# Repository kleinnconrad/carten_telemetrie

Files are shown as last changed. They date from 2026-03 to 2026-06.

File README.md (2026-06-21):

# Carten Telemetrie

## Inhaltsverzeichnis
* [1. Projektbeschreibung und Spezifikationen](#1-projektbeschreibung-und-spezifikationen)
* [2. Stückliste (Bill of Materials)](#2-stueckliste-bill-of-materials)
* [3. Schaltplan und Systemarchitektur](#3-schaltplan-und-systemarchitektur)
* [4. Implementierung und Aufbau](#4-implementierung-und-aufbau)
  * [4.1 Software und Firmware-Kompilierung](#41-software-und-firmware-kompilierung)
  * [4.2 Elektrische Verkabelung](#42-elektrische-verkabelung)
  * [4.3 Mechanische Integration](#43-mechanische-integration)
* [5. Betriebsmodus und Datenauswertung](#5-betriebsmodus-und-datenauswertung)
* [6. CI/CD: Reddit-Feedback-Synchronisation](#6-cicd-reddit-feedback-synchronisation)

## 1. Projektbeschreibung und Spezifikationen

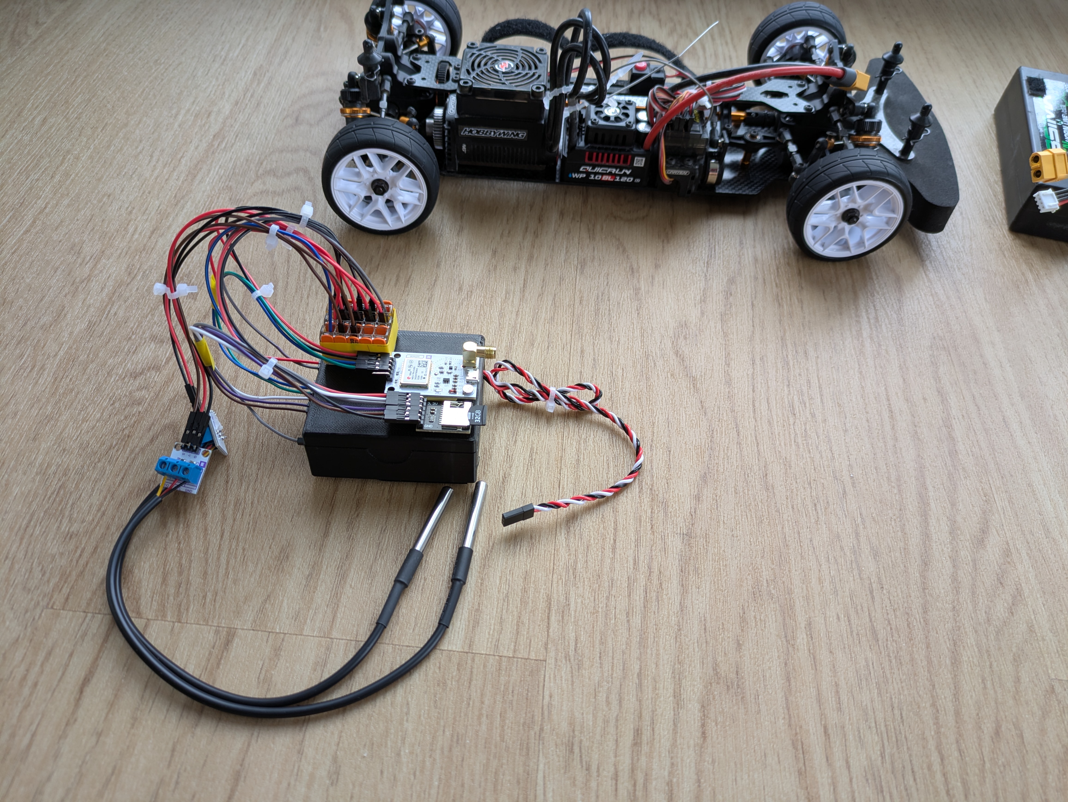
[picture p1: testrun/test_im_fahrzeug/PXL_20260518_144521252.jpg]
Test im Fahrzeug - Setup 1
 Carten Telemetrie Setup im Fahrzeug

Entwicklung eines lokalen Telemetriesystems für das ferngesteuerte Modellfahrzeug Carten T410R . Das System erfasst dynamische und thermische Parameter während des Fahrbetriebs.

**Erfasste Metriken und Spezifikationen:**
* **Temperatur:** Erfassung von Motor- und ESC-Temperaturen (Messbereich -55°C bis +125°C, Auflösung 12-Bit) über den 1-Wire-Bus.
* **Drehzahl:** RPM-Erfassung der Kardanwelle mittels Hall-Effekt-Sensor und Neodym-Magnet (Hardware-gestützter Pulse Counter).
* **Geodaten:** Aufzeichnung von Längen- und Breitengrad sowie der absoluten Geschwindigkeit (GNSS/GPS-Satellitendaten via NMEA 0183-Protokoll, Updaterate 1 Hz bis 10 Hz konfigurierbar).

**Architektur-Variante:**
* Ausschließliches Offline-Logging auf einer lokalen MicroSD-Karte. Zur Vermeidung von Latenzen und Verbindungsabbrüchen findet keine Datenübertragung über drahtlose Netzwerke statt.

## 2. Stückliste (Bill of Materials)
Für die Nachkonstruktion sind zwingend die folgenden Bauteile oder äquivalente Spezifikationen zu verwenden:

| Komponente | Spezifikation / Typ | Funktion im System |
| :--- | :--- | :--- |
| Microcontroller | ESP32 Dev Board (30-Pin Variante, z.B. NodeMCU) | Zentrale Ingestion und Verarbeitung der Sensorik |
| Erweiterungsboard | ESP32 Terminal Breakout Board (30-Pin) | Sichere Kontaktierung der Jumper-Kabel ohne Löten |
| GPS-Modul | BN-220 (u-blox M8N) | Bereitstellung der Geodaten (Baudrate 9600) |
| Speichermodul | MicroSD-Karten-Modul (SPI) | Persistenter Datenspeicher (zwingend 3.3V Logik) |
| Temperatursensor | DS18B20 (TO-92 oder wasserdicht) | 2x Sensoren zur Temperaturüberwachung (Motor, ESC) |
| Drehzahlsensor | Hall-Sensor Modul (A3144) | Detektion von Magnetfeldänderungen |
| Magnet | Neodym-Magnet (3x2mm) | Rotierender Impulsgeber an der Kardanwelle |
| Stromversorgung | 3-Pin Servokabel (JR-Stecker) | 5V Spannungsabgriff über das BEC des RC-Empfängers |

## 3. Schaltplan und Systemarchitektur
Alle Hardwarekomponenten nutzen eine gemeinsame Masse (GND) zur Vermeidung von Floating-Potenzialen. Die serielle UART-Verbindung zwischen ESP32 und GPS-Modul erfordert eine physikalische Kreuzung der Leitungen (TX an RX, RX an TX). Der Spitzenstrombedarf des Gesamtsystems liegt bei etwa 200 mA bis 250 mA.

| Komponente | Interface | ESP32 Pin | Sensor Pin | Bemerkung |
| :--- | :--- | :--- | :--- | :--- |
| RC-Empfänger| Power | `VIN` | 5V (Rot) | Parasitäre Versorgung über ESC/Empfänger (BEC) |
| | | `GND` | GND (Schwarz)| Referenzpotenzial |
| GPS Modul| UART 2 | `GPIO 16` (RX2) | TX | VCC-Spannungsversorgung zwingend über 3.3V des ESP32 |
| | | `GPIO 17` (TX2) | RX | |
| MicroSD-Modul | SPI | `GPIO 23`, `19`, `18`, `5` | MOSI, MISO, SCK, CS | VCC-Spannungsversorgung zwingend über 3.3V des ESP32 |
| DS18B20 | 1-Wire | `GPIO 4` | DQ (Daten) | Parallelschaltung beider Sensoren |
| A3144 Hall-Sensor| Dig. Out | `GPIO 2` | DO (Signal) | Anbindung an ESP32 PCNT (Pulse Counter) |

*(Der detaillierte visuelle Schaltplan befindet sich im Verzeichnis `/schaltplan`.)*

## 4. Implementierung und Aufbau

### 4.1 Software und Firmware-Kompilierung
* **Umgebung:** Die Kompilierung erfordert PlatformIO oder die Arduino IDE.
* **Bibliotheken:** Zur Übersetzung des Quellcodes müssen `TinyGPSPlus`, `OneWire` und `DallasTemperature` im Library-Manager installiert sein.
* **Flash-Vorgang:** Die Firmware ist via USB-Schnittstelle auf den ESP32 zu überspielen. Bei Boot-Problemen ist der serielle Output (`115200` Baud) auf Initialisierungsfehler (z.B. SD-Karte nicht gefunden) zu prüfen.

### 4.2 Elektrische Verkabelung
* Der ESP32 ist auf das Terminal-Breakout-Board aufzustecken. Alle Jumper-Kabel werden zwingend in den Schraubklemmen des Breakout-Boards fixiert, um vibrationsresistente Verbindungen zu gewährleisten.
* Das Servokabel ist polungsrichtig über Jumper-Kabel mit den `VIN`- (5V) und `GND`-Klemmen zu verschrauben und an einen freien Port des RC-Empfängers anzuschließen.
* Die Verbindung von GPS, SD-Modul, Hall-Sensor und Temperatursensoren ist gemäß der dokumentierten Pin-Belegung mittels Jumper-Kabeln und den Klemmen des Breakout-Boards vorzunehmen.
* Bei Mehrfachbelegungen (z. B. der Zusammenführung mehrerer GND- oder 3.3V-Leitungen der Sensoren) sind WAGO-Klemmen einzusetzen. Zur Vermeidung von Wackelkontakten bei Vibrationen ist der korrekte Sitz in den Klemmen zu prüfen.

### 4.3 Mechanische Integration
* **Zentraleinheit:** Die Befestigung des ESP32-Gehäuses im Chassis erfolgt über verschraubte Trägerplatten oder Klettband.
* **GPS:** Das GPS-Modul muss horizontal montiert werden. Die Keramik-Antenne muss ungehindert nach oben zeigen.
* **Drehzahlmessung:** Der Neodym-Magnet ist adhäsiv (z.B. Sekundenkleber oder Epoxidharz) auf der Kardanwelle zu fixieren. Ein entsprechendes Gegengewicht auf der gegenüberliegenden Seite der Welle verhindert Unwuchten bei hohen Rotationsgeschwindigkeiten. Der Hall-Sensor ist mit einem Spaltmaß von maximal 2 mm über dem Magneten starr zu positionieren.
* **Temperaturen:** Die DS18B20-Sensoren sind mit Wärmeleitkleber an ESC und Motorgehäuse anzubringen.

## 5. Betriebsmodus und Datenauswertung
* **Boot-Sequenz:** Das System startet autonom beim Einschalten des RC-Fahrzeugs. Nach erfolgreicher Initialisierung des SPI-Busses beginnt der Schreibvorgang.
* **Logging-Zyklus:** Die Sensordaten werden mit einer Frequenz von 2 Hz auf die MicroSD-Karte geschrieben. Die Limitierung auf 2 Hz verhindert Schreib-Puffer-Überläufe (Buffer Overruns) der SD-Karte.
* **Datenformat:** Die Ausgabe erfolgt als standardisierte CSV- oder JSON-Datei auf einer FAT32-formatierten Partition.
* **Post-Processing:** Nach Abschluss der Fahrt ist die MicroSD-Karte manuell zu entnehmen. Die Rohdaten können in Tabellenkalkulationsprogrammen oder Analyse-Skripten visualisiert und evaluiert werden.

## 6. CI/CD: Reddit-Feedback-Synchronisation
Eine konfigurierte GitHub Action dient der Extraktion von externem Projektfeedback aus dem verlinkten Reddit-Thread.

### Architektur
* **Python-Skript (`scripts/fetch_reddit.py`):** Verantwortlich für den Abruf des Reddit-RSS-Feeds und die HTML-Bereinigung der Kommentare.
* **Automatisierung (`.github/workflows/reddit-sync.yml`):** Der Cronjob triggert die Pipeline arbeitstäglich um 08:00 UTC.
* **Output-Handling:** Neu erfasste Kommentare werden in die Datei `reddit/reddit_feedback.md` geschrieben und durch die Action automatisch im `main`-Branch committet.

### Manueller Sync
Zur sofortigen Datensynchronisation:
* Im GitHub-Repository den Tab "Actions" öffnen.
* Den Workflow "Fetch Reddit Feedback" selektieren.
* "Run workflow" ausführen. Die Markdown-Datei wird daraufhin aktualisiert.

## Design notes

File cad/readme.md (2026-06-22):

# ESP32 Sensor-Station und Gehäuse

## Inhaltsverzeichnis
* [1. Übersicht](#1-übersicht)
* [2. Dateiliste](#2-dateiliste)
* [3. Hardware-Komponenten](#3-hardware-komponenten)
* [4. Druckparameter und Material](#4-druckparameter-und-material)
* [5. Montagehinweise](#5-montagehinweise)
* [6. Quellen](#6-quellen)

## 1. Übersicht
Dieser Ordner enthält die 3D-Druck-Dateien (STL) für die Fertigung der ESP32-Sensor-Station. Das mechanische Konzept besteht aus einem Schutzgehäuse für den Mikrocontroller und einem passgenauen Trägerboard zur Montage der Sensor- und Speichermodule innerhalb des RC-Chassis. Ziel ist der Schutz vor mechanischen Stößen, Staub und Spritzwasser sowie die Zugentlastung der Kabel.

## 2. Dateiliste

| Dateiname | Beschreibung | Herkunft |
| :--- | :--- | :--- |
| `esp32-30pin-breakoutboard-case.stl` | Unteres Gehäuseelement für das ESP32 Development Board (30-Pin Variante) inklusive des Terminal-Breakout-Boards. | Extern |
| `esp32-30pin-breakoutboard-lid.stl` | Deckel für das ESP32-Gehäuse mit Snap-Fit-Mechanismus (Einrast-Verschluss). | Extern |

## 3. Hardware-Komponenten
Die CAD-Konstruktion ist maßlich exakt auf folgende Hardware ausgelegt:
* Mikrocontroller: ESP32 Development Board (30 Pins, z.B. Freenove oder NodeMCU)
* Erweiterung: Terminal-Breakout-Board für 30-Pin ESP32 (Schraubklemmen)
* Sensoren: 2x DS18B20 (TO-92 Bauform oder vorkonfektioniert)
* Speicher: 1x MicroSD-Karten-Modul (Standard-SPI-Modul)
* Ortung: 1x GPS-Modul (BN-220, Maße: 22x20x6 mm)

## 4. Druckparameter und Material
Aufgrund der thermischen Belastung im RC-Fahrzeug (Nähe zu Motor und ESC) sowie der mechanischen Vibrationen gelten folgende Vorgaben für die additive Fertigung:

* **Material:** PETG, ASA oder ABS (PLA ist wegen der niedrigen Glasübergangstemperatur von ca. 60°C nicht zulässig).
* **Schichthöhe (Layer Height):** 0.20 mm für ein optimales Verhältnis aus Stabilität und Druckzeit.
* **Fülldichte (Infill):** Mindestens 30% (Gyroid oder Cubic Pattern), um strukturelle Integrität bei Stößen zu gewährleisten.
* **Wandlinien (Perimeters):** 3 bis 4 Linien zur Erhöhung der Biegesteifigkeit.
* **Toleranzen:** Das Modell beinhaltet ein Spaltmaß von 0.2 mm für den Snap-Fit-Deckel. Bei Überextrusion muss der Fluss (Flow Rate) im Slicer kalibriert werden.

## 5. Montagehinweise
* Die Platinen (GPS, SD-Modul) werden mit M2- oder M2.5-Schrauben auf der Trägerplatte `sensor_board_.stl` fixiert. Bei Bedarf sind Heiß-Einpressmuttern (Threaded Inserts) zu verwenden.
* Die Antenne des BN-220 GPS-Moduls (keramische Oberseite) muss zwingend nach oben zeigen und darf nicht durch Carbon- oder Metallbauteile des Chassis verdeckt werden.
* Kabeldurchführungen am Gehäuse müssen nach Abschluss der Verkabelung zur Zugentlastung mit einem Tropfen Schmelzklebstoff gesichert werden.

## 6. Quellen
* Modell: [ESP32 30-pin breakout board case + snap fit lid](https://www.printables.com/model/856471-esp32-30-pin-breakout-board-case-snap-fit-lid/files)
* Ersteller: [@Goofee_2018635 auf Printables](https://www.printables.com/@Goofee_2018635)

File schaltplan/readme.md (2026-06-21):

# RC-Telemetrie-System

## Inhaltsverzeichnis
* [1. System-Architektur](#1-system-architektur)
* [2. Schaltplan](#2-schaltplan)
* [3. Pin-Mapping](#3-pin-mapping)
* [4. Stromversorgung](#4-stromversorgung)
* [5. Schaltplan Generierung](#5-schaltplan-generierung)
* [6. Betrieb](#6-betrieb)

Dieses System erfasst Telemetriedaten (Geschwindigkeit, Drehzahl, Temperaturen) in einem RC-Fahrzeug als lokales Data-Logging.

## 1. System-Architektur
* Betriebsmodus: Batch-Logging auf MicroSD-Karte.
* GPS-Tracking: Ein GPS-Modul liefert Geodaten und Geschwindigkeitswerte via NMEA-Protokoll (Hardware-UART).
* Logging: Die MicroSD-Karte dient als primärer Speicher.
* Sensor-Auslesen: Die Erfassung erfolgt asynchron. Impulse des Hall-Sensors werden über einen Hardware-Zähler (PCNT) registriert.

## 2. Schaltplan

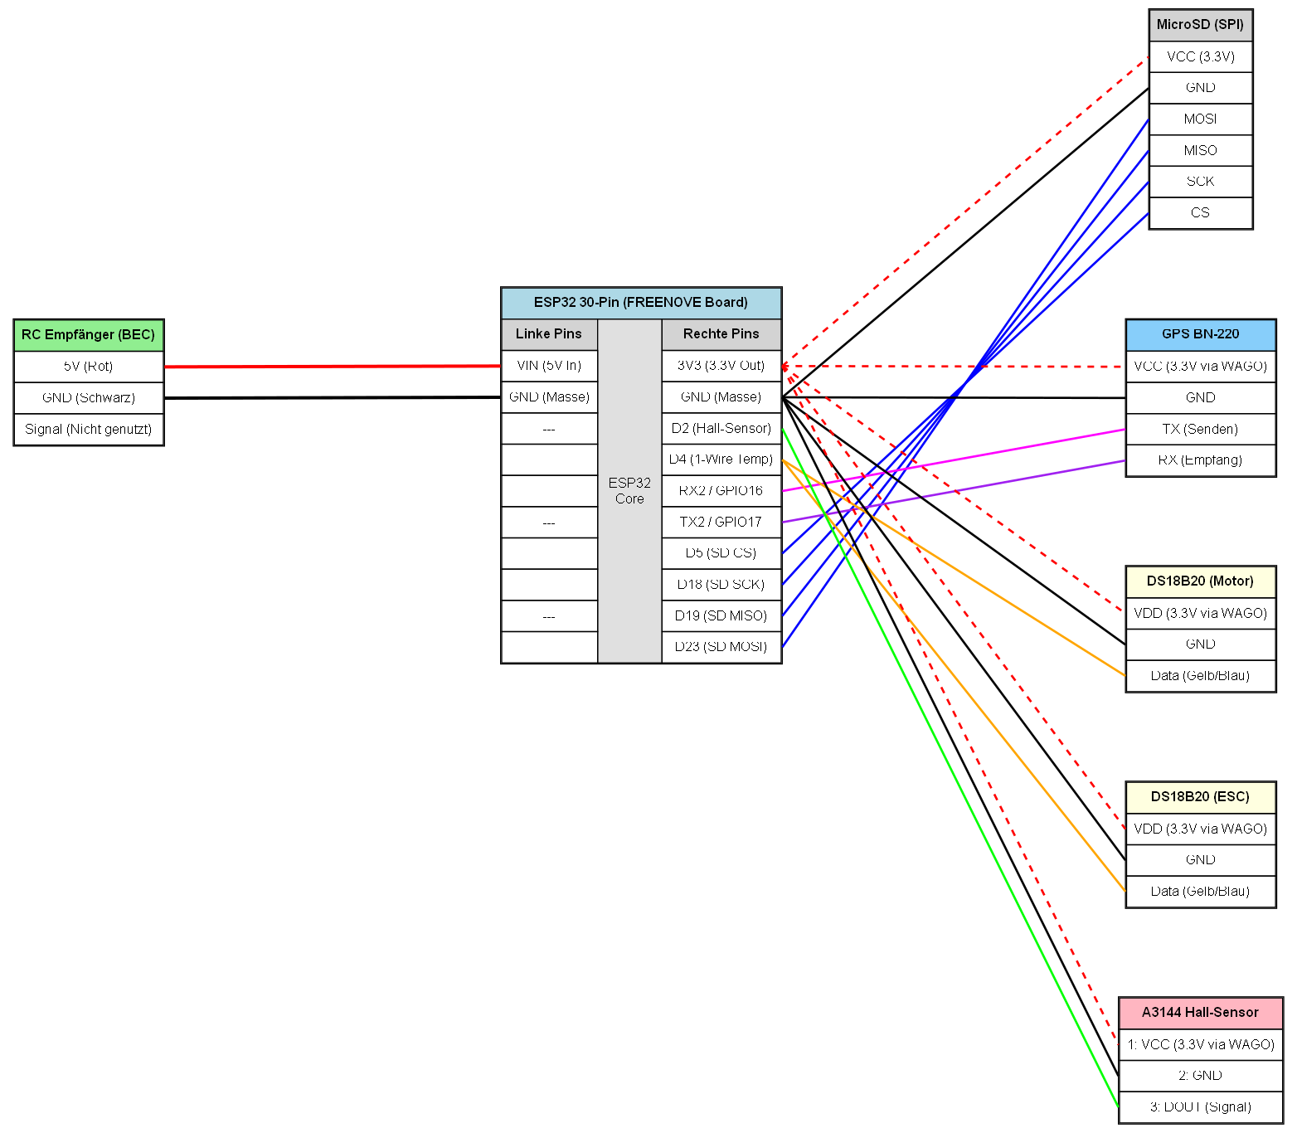
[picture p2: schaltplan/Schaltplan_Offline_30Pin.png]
Schaltplan Offline


## 3. Pin-Mapping
Alle Komponenten benötigen eine gemeinsame Masse (GND). Serielle Verbindungen erfordern gekreuzte Leitungen (TX an RX, RX an TX).

| Komponente | Interface | ESP32 Pin | Sensor Pin | Bemerkung |
| :--- | :--- | :--- | :--- | :--- |
| RC-Empfänger | Power | `VIN` | 5V (Rot) | Versorgung über ESC/Empfänger |
| | | `GND` | GND (Schwarz)| Gemeinsame Masse |
| GPS Modul | UART 2 | `GPIO 16` (RX2) | TX | VCC an 3.3V ESP32 |
| | | `GPIO 17` (TX2) | RX | |
| MicroSD-Modul | SPI | `GPIO 23`, `19`, `18`, `5` | MOSI, MISO, SCK, CS | VCC an 3.3V ESP32 |
| DS18B20 (Motor)| 1-Wire | `GPIO 4` | DQ | |
| DS18B20 (ESC)| 1-Wire | `GPIO 4` | DQ | Parallelschaltung |
| A3144 Hall-Sensor| Digital Out | `GPIO 2` | DO | PCNT-Nutzung |

## 4. Stromversorgung
ESP32 und Sensorik benötigen 150-250 mA. Die Versorgung erfolgt über den Motorregler (ESC) und Empfänger.
1. Anschluss eines Servokabels an den RC-Empfänger.
2. Rotes Kabel (5V) an den VIN-Pin des ESP32.
3. Schwarzes Kabel (GND) an den GND-Pin des ESP32.

## 5. Schaltplan Generierung
Der Schaltplan wird mit Python und `uv` erstellt.

1. System-Abhängigkeit (Alpine Linux):
   ```bash
   sudo apk add graphviz
   ```
2. Tool `uv` herunterladen:
   ```bash
   curl -LsSf https://astral.sh/uv/install.sh | sh
   source $HOME/.local/bin/env
   ```
3. Skript ausführen:
   ```bash
   uv run --with graphviz schaltplan.py
   ```

## 6. Betrieb
1. Boot: Systemstart bei Einschalten des RC-Fahrzeugs.
2. Log: Speicherung der Sensordaten mit 2 Hz auf der MicroSD-Karte.
3. Analyse: Manuelles Einlesen der MicroSD-Karte.

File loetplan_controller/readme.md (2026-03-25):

# RC-Telemetrie-System

Dieses System erfasst hochfrequente Telemetriedaten (Geschwindigkeit, Drehzahl, Temperaturen) in einem RC-Fahrzeug und streamt diese in Echtzeit über ein Mobilfunknetz (LTE) an ein Cloud-Backend (via MQTT). Die Architektur ist auf höchste Zuverlässigkeit und Systemsicherheit ausgelegt, inklusive einer vom RC-Antrieb komplett isolierten Stromversorgung.

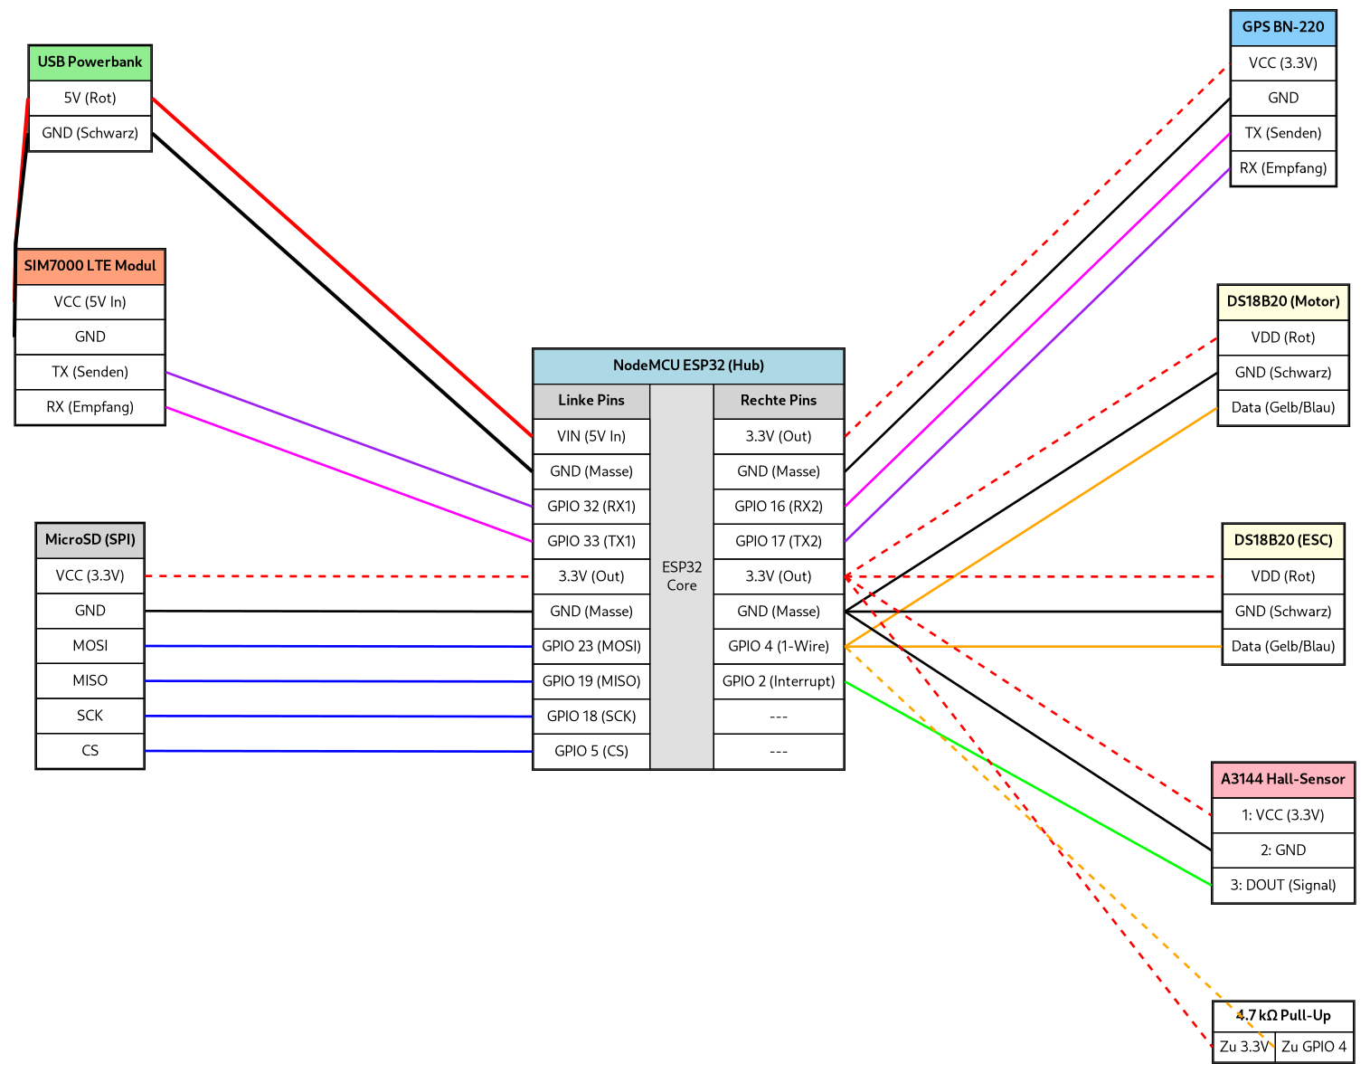
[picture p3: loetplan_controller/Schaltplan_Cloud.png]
schaltplan2


## 1. System-Architektur

* **Isolierte Stromversorgung:** Die gesamte Telemetrie-Elektronik wird über eine autarke 5V USB-Powerbank versorgt. Stromspitzen des LTE-Modems (bis zu 2A) können so keinen Brownout des RC-Empfängers verursachen.
* **Live-Streaming (LTE & MQTT):** Daten werden asynchron als JSON-Payloads via MQTT über ein SIM7000G LTE-Modul an die Cloud gesendet.
* **GPS Tracking:** Ein dediziertes GPS-Modul liefert echte Geodaten und hochpräzise Geschwindigkeitswerte via NMEA-Protokoll (Hardware-UART).
* **Lokales Backup (Ringpuffer):** Die MicroSD-Karte fungiert über den SPI-Bus als Fallback. Bei Verbindungsabbrüchen im Mobilfunknetz gehen keine Speedrun-Daten verloren.
* **Asynchrones Sensor-Auslesen:** Zeitintensive Operationen (wie die 750ms Wandlungszeit der DS18B20 1-Wire Sensoren) blockieren niemals den Main-Loop.

## 2. Pin-Mapping (Verkabelung)

**WICHTIG:** Alle Komponenten müssen sich eine gemeinsame Masse (**GND**) teilen. RX- und TX-Leitungen bei seriellen Verbindungen müssen immer überkreuzt angeschlossen werden (TX an RX, RX an TX).

| Komponente | Interface | ESP32 Pin | Sensor Pin | Bemerkung |
| :--- | :--- | :--- | :--- | :--- |
| **USB Powerbank** | Power | `VIN` | 5V Out | Speist ESP32 und LTE parallel |
| **LTE Modul (SIM7000)** | UART 1 | `GPIO 32` (RX1) | TX | VCC direkt an 5V Powerbank! |
| | | `GPIO 33` (TX1) | RX | |
| **GPS Modul (BN-220)**| UART 2 | `GPIO 16` (RX2) | TX | VCC an 3.3V vom ESP32 |
| | | `GPIO 17` (TX2) | RX | |
| **MicroSD-Modul** | SPI | `GPIO 23` | MOSI | |
| | | `GPIO 19` | MISO | |
| | | `GPIO 18` | SCK | |
| | | `GPIO 5` | CS | |
| **DS18B20 (Motor)** | 1-Wire | `GPIO 4` | DQ (Daten) | Benötigt 4.7kΩ Pull-Up an 3.3V |
| **DS18B20 (ESC)** | 1-Wire | `GPIO 4` | DQ (Daten) | Parallel zum Motor-Sensor schalten |
| **A3144 Hall-Sensor**| Digital Out | `GPIO 2` | DO (Signal) | Nutzt Hardware-Interrupt (`FALLING`) |

## 3. Autarke Stromversorgung (Power-Management)

Die zuverlässige Stromversorgung ist der kritischste Punkt dieses Cloud-Telemetrie-Systems. Das LTE-Modem (SIM7000) benötigt beim Senden im Mobilfunknetz kurzzeitig Stromspitzen von **bis zu 2 Ampere**. Würde man das Modem direkt an den 5V-Ausgang des ESP32 anschließen, käme es sofort zu einem Spannungsabfall (Brownout) und der Controller würde unkontrolliert neu starten. 

Um dies zu verhindern, nutzen wir eine isolierte Parallel-Schaltung mittels eines **USB Breakout-Boards**. 

### Benötigte Komponenten
* 1x Standard USB-Powerbank (5V, min. 2.1A Output)
* 1x USB Breakout-Board (Passend zum Anschluss der Powerbank, meist USB-A oder USB-C)
* Kupferlitze (Empfehlung: AWG 22 für das LTE-Modul, um Kabelwiderstände zu minimieren)

### Physischer Aufbau (Die 5V-Weiche)

Das Breakout-Board fungiert als Y-Verteiler, der den ESP32 und das LTE-Modem unabhängig voneinander aus derselben Quelle speist:

1. **VCC (5V Pluspol):**
   * Nimm zwei rote Kabel (ein dickeres für LTE, ein Standard-Kabel für den ESP32).
   * Verzwirble die blanken Kupferenden beider Kabel miteinander.
   * Stecke die verzwirbelten Enden gemeinsam durch das Pad mit der Aufschrift `VCC` (oder `5V`) auf dem Breakout-Board und verlöte sie großzügig.
   * Führe das eine Kabel an den `VIN` (oder 5V) Pin des ESP32 und das andere an den `VCC` (5V In) Pin des LTE-Moduls.

2. **GND (Gemeinsame Masse):**
   * Wiederhole den exakt gleichen Vorgang mit zwei schwarzen Kabeln am `GND`-Pad des Breakout-Boards.
   * Führe ein Kabel an einen `GND` Pin des ESP32 und das andere an den `GND` Pin des LTE-Moduls. 
   * *Wichtig: Alle Komponenten des Systems (Sensoren, GPS, SD-Karte) müssen zwingend über den ESP32 mit diesem GND verbunden sein (Common Ground), da sonst die serielle Datenübertragung fehlschlägt.*

3. **Daten-Pins (D+ / D-):**
   * Diese Pins auf dem Breakout-Board werden komplett ignoriert, da die USB-Verbindung rein der Stromversorgung dient.

Sobald das Breakout-Board in die Powerbank gesteckt wird, fahren beide Module parallel hoch, ohne sich bei Stromspitzen gegenseitig zu beeinflussen.

## 4. Schaltplan generieren (mit `uv`)

Um den visuellen Lötplan als PNG zu generieren, nutzen wir Python und das Tool `uv`, um die Abhängigkeit (`graphviz`) nicht global im System installieren zu müssen.

**graphviz:**

1. System-Abhängigkeit installieren (Alpine Linux):
   ```bash
   sudo apk add graphviz
   ```

2. Tool `uv` herunterladen und Pfad laden:
   ```bash
   curl -LsSf [https://astral.sh/uv/install.sh](https://astral.sh/uv/install.sh) | sh
   source $HOME/.local/bin/env
   ```

3. Skript ausführen:
   ```bash
   uv run --with graphviz loetplan.py
   ```

## 5. Betrieb

1. **Boot:** Nach dem Verbinden der USB-Powerbank initialisiert der ESP32 die SD-Karte und wartet auf einen GPS-Fix.
2. **Connect:** Das Modem wählt sich ins LTE-Netz ein und baut die TCP-Verbindung zum MQTT-Broker der Cloud auf.
3. **Stream:** Sensordaten werden kontinuierlich erfasst und in Echtzeit an das Cloud-Dashboard gepusht. 
4. **Analyse:** Die Auswertung der Fahrt (Geschwindigkeitskurven, Temperatur-Warnungen) erfolgt live über das Cloud-Frontend (z.B. Grafana), ein lokaler Download der CSV ist nur im Fehlerfall nötig.

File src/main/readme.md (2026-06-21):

# Firmware: RC Telemetrie

## Inhaltsverzeichnis
* [1. Architektur und Firmware-Variante](#1-architektur-und-firmware-variante)
* [2. Kern-Funktionen und Module](#2-kern-funktionen-und-module)
* [3. Datenstruktur und Speicherformat](#3-datenstruktur-und-speicherformat)
* [4. Hardware-Interrupts (PCNT)](#4-hardware-interrupts-pcnt)
* [5. Bibliotheken und Abhängigkeiten](#5-bibliotheken-und-abhängigkeiten)

Diese Firmware ist exklusiv für den ESP32 als lokales Data-Logging-System konzipiert. Sie erfasst zyklisch GPS-Daten, Drehzahlen und Systemtemperaturen.

## 1. Architektur und Firmware-Variante
* `main_offline`: Die Software arbeitet im Batch-Betrieb. Es findet keine drahtlose Kommunikation (weder WiFi noch Bluetooth oder LTE) statt. Der ESP32 fungiert als reiner Sensor-Hub und schreibt die ermittelten Payloads mit einer Frequenz von 2 Hz auf die angeschlossene MicroSD-Karte.
* **Main-Loop:** Die `loop()`-Schleife ist streng blockierungsfrei (non-blocking) implementiert. Verzögerungen durch `delay()` sind bis auf minimale Entprell-Logiken untersagt. Das Timing erfolgt über `millis()`-basierte Zustandsmaschinen.

## 2. Kern-Funktionen und Module
* **Asynchrone Sensorabfrage:** Das Parsen der NMEA-Datensätze des GPS-Moduls erfolgt zeichenweise asynchron. Temperaturmessungen des 1-Wire-Busses werden asynchron angefragt; der Bus blockiert während der Konvertierungszeit (ca. 750 ms für 12-Bit Auflösung) nicht die restliche Codeausführung.
* **Hardware UART:** Zur seriellen Kommunikation mit dem GPS-Modul wird zwingend die Hardware-Serial-Schnittstelle (`UART 2`) an den Pins `GPIO 16` und `17` verwendet. `SoftwareSerial` ist aus Leistungsgründen nicht zulässig.

## 3. Datenstruktur und Speicherformat
Die erhobenen Sensordaten werden formatiert auf der MicroSD-Karte abgelegt.
* **Dateisystem:** FAT32 (SDHC-Karten bis 32 GB empfohlen).
* **Format:** Jeder Log-Eintrag besteht wahlweise aus einem JSON-Objekt oder einer durch Kommata getrennten Zeile (CSV).
* **Metriken:** Timestamps (aus GPS-RTC bezogen), Motor-Temperatur (°C), ESC-Temperatur (°C), Drehzahl (RPM), GPS-Koordinaten (Lat/Lon), Satellitenanzahl (HDOP-Wert zur Genauigkeitsprüfung).

## 4. Hardware-Interrupts (PCNT)
Für die exakte Erfassung der Drehzahl über den A3144 Hall-Sensor wird das PCNT (Pulse Counter) Peripheriemodul des ESP32 genutzt. 
* Im Gegensatz zu softwarebasierten GPIO-Interrupts, die bei hohen Frequenzen zum Absturz des Schedulers führen können, zählt das PCNT-Modul Impulse autark auf der Hardware-Ebene. 
* Die Drehzahl (RPM) wird über eine `timeDelta`-Berechnung ermittelt: Anzahl der Impulse im Messintervall, skaliert auf eine Minute.

## 5. Bibliotheken und Abhängigkeiten
Folgende externe Bibliotheken sind für den Build-Prozess (Kompilierung über PlatformIO oder Arduino IDE) zwingend erforderlich:

* `TinyGPSPlus`: Effizientes Parsen der eingehenden NMEA-Rohdaten.
* `OneWire`: Protokoll-Ebene für den Bus der Temperatursensoren.
* `DallasTemperature`: Höherwertige Abstraktionsschicht zur Adressierung und Auslesung der DS18B20-ICs.
* `SPI` und `SD`: Core-Bibliotheken für den Dateizugriff auf das MicroSD-Modul.

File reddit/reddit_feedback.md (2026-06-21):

# Reddit Feedback: Telemetrie-System (RSS Sync)

## Inhaltsverzeichnis
* [1. Letzter Synchronisationszeitpunkt](#1-letzter-synchronisationszeitpunkt)
* [2. Kommentare](#2-kommentare)

## 1. Letzter Synchronisationszeitpunkt
03.04.2026 20:24:24

## 2. Kommentare

**u/Basic-You7791** [schrieb](https://www.reddit.com/r/esp32/comments/1s9dydh/building_a_live_telemetry_system_for_my_100kmh_rc/):
> Hallo r/esp32! Ich konstruiere derzeit ein RC-Fahrzeug (Carten T410R) im Maßstab 1:10 mit dem Ziel, Geschwindigkeiten von 100 km/h zu erreichen. Link: https://github.com/kleinnconrad/RC100.
> 
> Beruflich entwickle ich Datenanalyse-Plattformen. Daher ist die Erfassung von Live-Daten aus dem Fahrzeug ein Teil dieses Projekts. Ich besitze Erfahrung mit Datenplattformen, bin jedoch Anfänger im Bereich der eingebetteten Programmierung. Dies ist mein erstes Hardware/C++ Projekt.
> 
> Geplant ist der Einsatz eines ESP32 als IoT-Telemetriegerät im Fahrzeug. Ziel ist die Erfassung von Live-Daten während der Fahrten und deren Übertragung, um thermische Bedingungen und Leistungsgrenzen zu analysieren.
> 
> Da das ESP32-Ökosystem neu für mich ist, gehe ich von Fehlern in meinem ersten Entwurf aus.
> 
> Das Projekt ist auf GitHub veröffentlicht. Ich bitte um Überprüfung, Ratschläge oder Hinweise von erfahrenen Entwicklern.
> 
> Repository: https://github.com/kleinnconrad/carten_telemetrie
> 
> Die Dokumentation ist in deutscher Sprache verfasst.
> 
> Tipps zur Verarbeitung von Live-Datenströmen an einem bewegten Objekt bei 100 km/h sind willkommen.

**u/Plastic_Fig9225** [schrieb](https://www.reddit.com/r/esp32/comments/1s9dydh/building_a_live_telemetry_system_for_my_100kmh_rc/odnq4e3/):
> Der Code sollte in mehrere Tasks aufgeteilt werden, um Jitter bei der Datenerfassung zu vermeiden. MQTT kann unvorhersehbare Verzögerungen verursachen.
> Für die Drehzahlmessung empfiehlt sich die Nutzung des PCNT (Arduino) des ESP.
> Die Berechnung `int rpm = pulses * (60000 / ingestionInterval);` sollte zu `pulses * (60000 / (millis() - lastIngestionTime))` geändert werden, um zeitlichen Jitter zu berücksichtigen. Der Zeitstempel sollte so nah wie möglich am Auslesen der `pulses` genommen werden.
> Ein Timer kann genutzt werden, um die Datenerfassung in festen Intervallen durchzuführen, unabhängig vom Timing anderer Operationen.

**u/Basic-You7791** [schrieb](https://www.reddit.com/r/esp32/comments/1s9dydh/building_a_live_telemetry_system_for_my_100kmh_rc/odobii2/):
> Danke für den Hinweis zur Berechnungslogik und zum Impulszähler. Der Code wurde entsprechend aktualisiert.

**u/Plastic_Fig9225** [schrieb](https://www.reddit.com/r/esp32/comments/1s9dydh/building_a_live_telemetry_system_for_my_100kmh_rc/odptjd2/):
> Beim PCNT ist zu beachten, dass der Zähler automatisch auf null zurückgesetzt wird, wenn er den oberen oder unteren Grenzwert überschreitet. Um keine Impulse zu verlieren, kann folgende Logik angewendet werden:
> [Codebeispiel zur Behandlung des PCNT-Überlaufs]

**u/Basic-You7791** [schrieb](https://www.reddit.com/r/esp32/comments/1s9dydh/building_a_live_telemetry_system_for_my_100kmh_rc/odqkzd8/):
> Danke. Ich habe dies mit einem LLM diskutiert. Der Vorschlag wurde übernommen.

**u/Plastic_Fig9225** [schrieb](https://www.reddit.com/r/esp32/comments/1s9dydh/building_a_live_telemetry_system_for_my_100kmh_rc/ods93c3/):
> Die Telemetriedaten enthalten keine Geschwindigkeit. Das GPS liefert eine genaue Geschwindigkeit über Grund, die präziser ist als eine Ableitung aus Positionsdaten. Dies sollte integriert werden.

**u/Basic-You7791** [schrieb](https://www.reddit.com/r/esp32/comments/1s9dydh/building_a_live_telemetry_system_for_my_100kmh_rc/odtzz1m/):
> Danke für den Hinweis. Gemäß der Commit-Historie wurde dies nie implementiert.

**u/portugese_fruit** [schrieb](https://www.reddit.com/r/esp32/comments/1s9dydh/building_a_live_telemetry_system_for_my_100kmh_rc/odoepnc/):
> Das System sieht gut aus.

**u/Basic-You7791** [schrieb](https://www.reddit.com/r/esp32/comments/1s9dydh/building_a_live_telemetry_system_for_my_100kmh_rc/odoftb5/):
> Zustimmung.

**u/portugese_fruit** [schrieb](https://www.reddit.com/r/esp32/comments/1s9dydh/building_a_live_telemetry_system_for_my_100kmh_rc/odov0on/):
> An welchen Orten wird das Fahrzeug bewegt? Sind 100 km/h auf der Straße möglich?

**u/Basic-You7791** [schrieb](https://www.reddit.com/r/esp32/comments/1s9dydh/building_a_live_telemetry_system_for_my_100kmh_rc/odovbdp/):
> Parkplätze von großen Supermärkten außerhalb der Öffnungszeiten eignen sich dafür.

**u/jappiedoedelzak** [schrieb](https://www.reddit.com/r/esp32/comments/1s9dydh/building_a_live_telemetry_system_for_my_100kmh_rc/odohi8x/):
> Ein Blick auf ExpressRLS (https://www.expresslrs.org/) wird empfohlen. Es ist ein Open-Source-RC-System, das Telemetrie unterstützt.

**u/Basic-You7791** [schrieb](https://www.reddit.com/r/esp32/comments/1s9dydh/building_a_live_telemetry_system_for_my_100kmh_rc/odohx37/):
> Danke. Das System wird geprüft.

**u/G-EDM** [schrieb](https://www.reddit.com/r/esp32/comments/1s9dydh/building_a_live_telemetry_system_for_my_100kmh_rc/odo9ijv/):
> Welche Fragen bestehen bezüglich Datenübertragung und Datenerfassung? PCNT eignet sich für die Impulszählung, I2S ADC für analoge Datenerfassung. Für die Übertragung sollten DMA-Puffer genutzt werden. Daten sollten komprimiert werden, z. B. durch Packen von vier 8-Bit-Werten in einen 32-Bit-Integer.

**u/Basic-You7791** [schrieb](https://www.reddit.com/r/esp32/comments/1s9dydh/building_a_live_telemetry_system_for_my_100kmh_rc/odoesab/):
> Es ist geplant, Daten (GPS, Temperatur, Hall-Sensor) mit einer Abtastrate von 2 Hz zu erfassen und über LTE via MQTT in eine Cloud zu streamen. JSON-Payloads werden verwendet. I2S, DMA-Puffer und Bit-Packing sind für eine Rate von 2 Hz derzeit nicht erforderlich. Das Bit-Packing wird für mögliche Erweiterungen mit analogen Hochfrequenzsensoren vorgemerkt.

**u/G-EDM** [schrieb](https://www.reddit.com/r/esp32/comments/1s9dydh/building_a_live_telemetry_system_for_my_100kmh_rc/odoofo8/):
> Für 2 Hz sind diese Methoden nicht zwingend erforderlich.

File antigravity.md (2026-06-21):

# Projektkontext
Bei diesem Vorhaben handelt es sich um ein Hardwareprojekt auf Hobbyniveau. Die Zielgruppe besteht aus technisch interessierten Personen mit ingenieurwissenschaftlichen Grundlagenkompetenzen. Die gesamte Kommunikation hat sich zwingend an diesem fachlichen Niveau zu orientieren.

# Dokumentationsrichtlinien
* **Sprache:** Für sämtliche Dokumentationen innerhalb des Repositories ist die deutsche Sprache zu verwenden.
* **Formatierung:** Bullet Points (Listen zur Strukturierung) sind erlaubt und ausdrücklich erwünscht, um die Lesbarkeit zu erhöhen.
* **Inhaltsverzeichnis:** Sobald eine Markdown-Datei mehr als eine Überschrift enthält, ist zwingend ein Inhaltsverzeichnis (Table of Contents) an den Anfang zu stellen.
* **Emojis:** Im gesamten Repository ist auf Emojis zu verzichten.

# Sprachstil
* **Sachlichkeit:** Der Schreibstil hat streng sachlich, präzise und nüchtern zu sein.
* **Adjektive:** Die überflüssige Aufzählung oder redundante Aneinanderreihung von Adjektiven (z.B. "die schöne, aufregende, tolle...") ist strikt zu vermeiden.
* **Wortwahl:** Füllwörter und Superlative sind wegzulassen, sofern sie nicht für das technische Verständnis zwingend erforderlich sind.
* **Phrasen:** Die Verwendung von Phrasen, Redewendungen oder metaphorischen Umschreibungen ist untersagt.

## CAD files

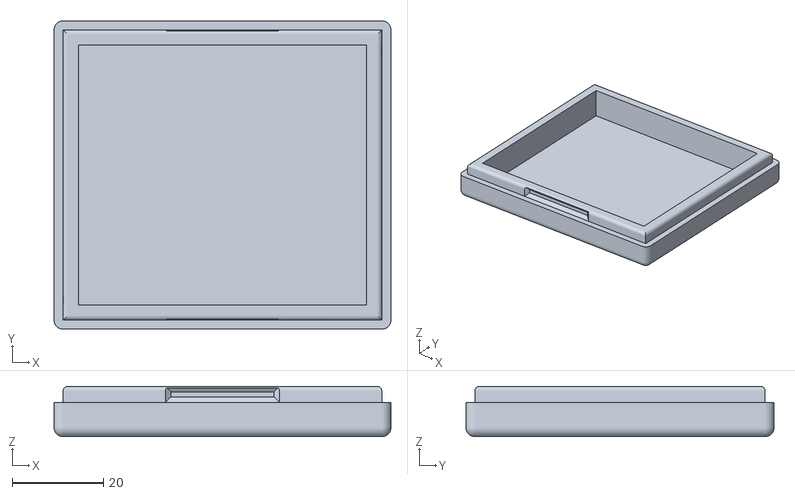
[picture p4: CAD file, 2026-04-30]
cad/esp32-30pin-breakoutboard-lid.stl
73.8 x 67.5 x 11.0

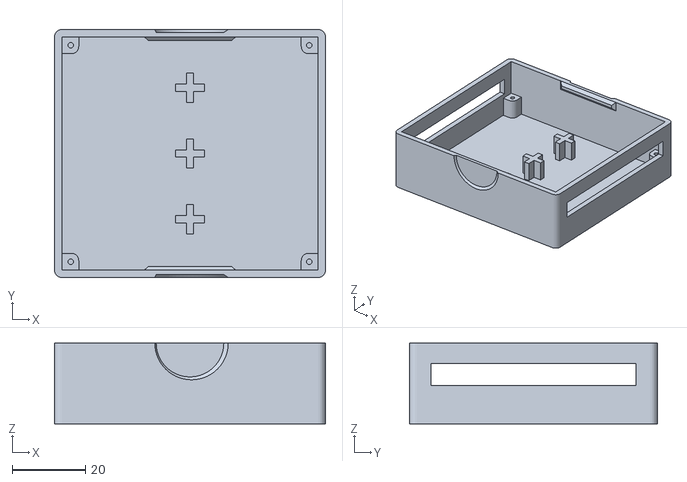
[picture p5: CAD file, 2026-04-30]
cad/esp32-30pin-breakoutboard-case.stl
73.8 x 67.5 x 22.0

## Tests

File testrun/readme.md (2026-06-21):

# Testprotokoll: In-Vehicle Integration

## Inhaltsverzeichnis
* [1. Testaufbau und Spezifikationen](#1-testaufbau-und-spezifikationen)
* [2. Prüfverfahren und Methodik](#2-prüfverfahren-und-methodik)
* [3. Testergebnisse und Validierung](#3-testergebnisse-und-validierung)
* [4. Visuelle Dokumentation](#4-visuelle-dokumentation)

## 1. Testaufbau und Spezifikationen
Der Integrationstest der Telemetrie-Einheit wurde im montierten Zustand im Fahrzeug-Chassis vollzogen.
* **Stromversorgung:** Die Energieversorgung des ESP32 erfolgte ausschließlich parasitär über den BEC-Port (Battery Eliminator Circuit) des RC-Empfängers bei einer nominalen Spannung von 5.0 V.
* **Datenspeicher:** Eine 16 GB SDHC-Karte (FAT32, Clustergröße 32 KB) wurde für das Logging verwendet.
* **Umgebung:** Das Fahrzeug wurde stationär unter freiem Himmel positioniert, um eine ungestörte Line-of-Sight für den Fix der Satelliten des GPS-Moduls zu garantieren.
* **Testdauer:** Der Testlauf dauerte exakt 180 Sekunden.

## 2. Prüfverfahren und Methodik
Der Test fokussierte sich auf die Verifikation von Systemstabilität und Datenintegrität unter realen mechanischen Integrationsbedingungen.
* Es wurde kontrolliert, ob der Einschaltstrom (Inrush Current) des ESP32 zu einem Reset oder einem Spannungsabfall ("Brownout") des Empfängers führt.
* Der Datendurchsatz auf dem SPI-Bus zum SD-Modul wurde im 2 Hz-Takt überwacht.
* Es wurde eine Störfestigkeitsprüfung bezüglich elektromagnetischer Interferenzen (EMI) zwischen dem Fahrtregler (ESC) und dem GPS-Modul durchgeführt.

## 3. Testergebnisse und Validierung
* **Stromversorgung:** Der Test war erfolgreich. Das BEC des Empfängers lieferte ausreichend Strom (Spitzen bis 250 mA) für den Bootvorgang. Brownout-Erkennungen des ESP32 blieben aus.
* **Datenaufzeichnung:** Das Logging auf die MicroSD-Karte verlief vollständig fehlerfrei. Es wurden keine verlorenen Schreibzyklen (Dropped Frames) verzeichnet.
* **Sensordaten:** Die in der Datei `log.csv` erfassten Parameter (Temperaturwerte in °C, GPS-Koordinaten) wurden einer Plausibilitätsprüfung unterzogen. Die Temperaturwerte lagen stabil im Umgebungsspektrum (ca. 22 °C), und der GPS-Fix erreichte eine akzeptable HDOP (Horizontal Dilution of Precision).

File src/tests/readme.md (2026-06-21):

# Testverfahren und Verifikation

## Inhaltsverzeichnis
* [1. Methodik und Akzeptanzkriterien](#1-methodik-und-akzeptanzkriterien)
* [2. Allgemeine Vorbereitung](#2-allgemeine-vorbereitung)
* [3. Phase 1: Systemstart](#3-phase-1-systemstart)
* [4. Phase 2A: Temperatursensor](#4-phase-2a-temperatursensor)
* [5. Phase 2B: Hall-Sensor](#5-phase-2b-hall-sensor)
* [6. Phase 3: MicroSD-Karte](#6-phase-3-microsd-karte)
* [7. Phase 4: GPS-Modul](#7-phase-4-gps-modul)

## 1. Methodik und Akzeptanzkriterien
Die nachfolgenden Testroutinen dienen der isolierten Hardware-Verifikation (Unit-Tests der Peripherie). Jede Komponente muss zwingend einzeln geprüft werden, bevor die vollständige Firmware aufgespielt wird.
Ein Test gilt als bestanden, wenn die Ausgabe im Seriellen Monitor präzise den definierten Erwartungswerten entspricht und keine Hardware-Timeouts gemeldet werden.

## 2. Allgemeine Vorbereitung
1. Den ESP32 über ein Daten-USB-Kabel (zwingend mit intakten D+/D- Leitungen) mit dem PC verbinden.
2. Die Arduino IDE öffnen und den jeweiligen Testcode in den Editor einfügen.
3. Im Menü `Werkzeuge` -> `Board`: Die Vorgabe `ESP32 Dev Module` auswählen.
4. Im Menü `Werkzeuge` -> `Port`: Die Zuweisung des erkannten COM-Ports (Windows) bzw. `/dev/ttyUSB*` (Linux/macOS) vornehmen.
5. Die Upload-Schaltfläche betätigen. Falls der Verbindungsaufbau stagniert, den `BOOT`-Taster am ESP32 für zwei Sekunden gedrückt halten.
6. Den Seriellen Monitor öffnen und die Baudrate exakt auf `115200` einstellen.

## 3. Phase 1: Systemstart
**Ziel:** Prüfung der ESP32-Grundfunktion, des seriellen Interfaces und des Flash-Vorgangs.
**Akzeptanzkriterium:** Der serielle Monitor gibt abwechselnd im Sekunden-Takt "LED AN" und "LED AUS" aus. Die Onboard-LED blinkt synchron.

```cpp
#include <Arduino.h>

const int LED_PIN = 2; 

void setup() {
  Serial.begin(115200);
  pinMode(LED_PIN, OUTPUT);
  Serial.println("Systemstart");
}

void loop() {
  digitalWrite(LED_PIN, HIGH);
  Serial.println("LED AN");
  delay(1000);
  
  digitalWrite(LED_PIN, LOW);
  Serial.println("LED AUS");
  delay(1000);
}
```

## 4. Phase 2A: Temperatursensor
**Ziel:** Verifikation der 1-Wire-Kommunikation. Anschluss des DS18B20-Sensors an Pin 4.
**Akzeptanzkriterium:** Die gemessene Temperatur wird in Celsius ausgegeben. Ein Auslesen des Werts `-127.00 C` indiziert einen Verbindungsabbruch oder Verdrahtungsfehler.

```cpp
#include <Arduino.h>
#include <OneWire.h>
#include <DallasTemperature.h>

const int ONE_WIRE_BUS = 4;
OneWire oneWire(ONE_WIRE_BUS);
DallasTemperature sensors(&oneWire);

void setup() {
  Serial.begin(115200);
  sensors.begin();
  Serial.println("Temperatur-Test");
}

void loop() {
  sensors.requestTemperatures(); 
  float temp = sensors.getTempCByIndex(0);
  
  Serial.print("Temperatur: ");
  Serial.print(temp);
  Serial.println(" C");
  
  delay(1000);
}
```

## 5. Phase 2B: Hall-Sensor
**Ziel:** Funktionsprüfung des Hardware-Interrupts am A3144 Hall-Sensor (Pin 2).
**Akzeptanzkriterium:** Bei manueller Annäherung des Neodym-Magneten an den Sensor wird exakt ein Impuls auf dem Seriellen Monitor registriert. Mehrfachauslösungen weisen auf Prellen hin (Bouncing).

```cpp
#include <Arduino.h>

const int HALL_PIN = 2;
volatile int magnetErkannt = 0;

void IRAM_ATTR countPulse() {
  magnetErkannt++;
}

void setup() {
  Serial.begin(115200);
  pinMode(HALL_PIN, INPUT_PULLUP);
  attachInterrupt(digitalPinToInterrupt(HALL_PIN), countPulse, FALLING);
  Serial.println("Bereit");
}

void loop() {
  if (magnetErkannt > 0) {
    Serial.print("Impulse: ");
    Serial.println(magnetErkannt);
    magnetErkannt = 0;
  }
  delay(100);
}
```

## 6. Phase 3: MicroSD-Karte
**Ziel:** Verifikation des SPI-Busses und der Lese-/Schreibzyklen. Das Modul muss zwingend über 3.3V versorgt werden.
**Akzeptanzkriterium:** Ausgabe der Bestätigung "Schreibvorgang abgeschlossen". Die SD-Karte (FAT32) enthält anschließend eine Datei `test.txt` mit dem Text "SD-Test erfolgreich".

```cpp
#include <Arduino.h>
#include <SPI.h>
#include <SD.h>

const int SD_CS_PIN = 5;

void setup() {
  Serial.begin(115200);
  
  if (!SD.begin(SD_CS_PIN)) {
    Serial.println("Fehler bei SD-Initialisierung");
    return;
  }
  
  File dataFile = SD.open("/test.txt", FILE_WRITE);
  if (dataFile) {
    dataFile.println("SD-Test erfolgreich");
    dataFile.close();
    Serial.println("Schreibvorgang abgeschlossen");
  } else {
    Serial.println("Fehler beim Dateizugriff");
  }
}

void loop() {}
```

## 7. Phase 4: GPS-Modul
**Ziel:** Evaluierung des Hardware-UART-Empfangs von NMEA-Datensätzen des BN-220 Moduls (RX an Pin 16, TX an Pin 17).
**Akzeptanzkriterium:** Der Monitor zeigt rohe NMEA-Sätze (z.B. `$GPRMC...`) an. Diese müssen unter freiem Himmel valide Koordinaten enthalten, andernfalls verbleiben die Datenfelder leer.

```cpp
#include <Arduino.h>
#include <HardwareSerial.h>

const int GPS_RX_PIN = 16;
const int GPS_TX_PIN = 17;
HardwareSerial SerialGPS(2);

void setup() {
  Serial.begin(115200);
  SerialGPS.begin(9600, SERIAL_8N1, GPS_RX_PIN, GPS_TX_PIN);
}

void loop() {
  while (SerialGPS.available()) {
    char c = SerialGPS.read();
    Serial.print(c);
  }
}
```

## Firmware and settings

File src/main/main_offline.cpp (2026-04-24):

#include <Arduino.h>
#include <SPI.h>
#include <SD.h>
#include <OneWire.h>
#include <DallasTemperature.h>
#include <HardwareSerial.h>
#include <TinyGPS++.h>
#include <driver/pcnt.h> // Die ESP32 Hardware-Zähler Bibliothek

// --- Pin Definitionen ---
const int SD_CS_PIN = 5;
const int ONE_WIRE_BUS = 4;
const int HALL_PIN = 2;
// LTE Pins 32 & 33 werden in der Offline-Variante nicht mehr benötigt
const int GPS_RX_PIN = 16;
const int GPS_TX_PIN = 17;

// --- Objekte ---
OneWire oneWire(ONE_WIRE_BUS);
DallasTemperature sensors(&oneWire);
TinyGPSPlus gps;
HardwareSerial SerialGPS(2); 

// --- States & Timing ---
unsigned long lastIngestionTime = 0;
const int ingestionInterval = 500; // 2 Hz Logging-Rate
unsigned long lastTempRequest = 0;
float currentTempMotor = 0.0;
float currentTempESC = 0.0;

// --- PCNT Hardware Zähler States ---
pcnt_unit_t pcnt_unit = PCNT_UNIT_0;
int16_t prevPulses = 0; 
const int16_t COUNTER_HIGH_LIMIT = 30000;

// --- Setup PCNT Hardware-Zähler ---
void setupPCNT() {
  pcnt_config_t pcnt_config = {
    .pulse_gpio_num = HALL_PIN,
    .ctrl_gpio_num = PCNT_PIN_NOT_USED,
    .lctrl_mode = PCNT_MODE_KEEP,
    .hctrl_mode = PCNT_MODE_KEEP,
    .pos_mode = PCNT_COUNT_DIS,   // Ignorieren, wenn der Magnet kommt (HIGH)
    .neg_mode = PCNT_COUNT_INC,   // Zählen, wenn das Signal abfällt (FALLING)
    .counter_h_lim = COUNTER_HIGH_LIMIT,
    .counter_l_lim = -1,
    .unit = pcnt_unit,
    .channel = PCNT_CHANNEL_0,
  };
  
  pcnt_unit_config(&pcnt_config);
  
  // Hardware-Filter gegen Störsignale/Vibrationen aktivieren
  pcnt_set_filter_value(pcnt_unit, 100); 
  pcnt_filter_enable(pcnt_unit);
  
  pcnt_counter_pause(pcnt_unit);
  pcnt_counter_clear(pcnt_unit);
  pcnt_counter_resume(pcnt_unit);
}

void setup() {
  Serial.begin(115200);
  SerialGPS.begin(9600, SERIAL_8N1, GPS_RX_PIN, GPS_TX_PIN);

  // Sensoren starten
  sensors.begin();
  sensors.setWaitForConversion(false);
  sensors.requestTemperatures();

  // Hall-Sensor Pullup aktivieren & Hardware-Zähler starten
  pinMode(HALL_PIN, INPUT_PULLUP); // EXTREM WICHTIG für den A3144!
  setupPCNT();

  // SD-Karte initialisieren
  if (SD.begin(SD_CS_PIN)) {
    Serial.println("SD OK - Offline Logging bereit");
  } else {
    Serial.println("SD Fehler! Bitte Karte prüfen.");
  }
  
  lastIngestionTime = millis();
}

void loop() {
  unsigned long currentMillis = millis();

  // 1. GPS Stream asynchron lesen
  while (SerialGPS.available() > 0) {
    gps.encode(SerialGPS.read());
  }

  // 2. Temperatur-Update-Zyklus (Asynchron)
  if (currentMillis - lastTempRequest >= 800) {
    currentTempMotor = sensors.getTempCByIndex(0);
    currentTempESC = sensors.getTempCByIndex(1);
    sensors.requestTemperatures();
    lastTempRequest = currentMillis;
  }

  // 3. Data Logging Pipeline
  unsigned long timeDelta = currentMillis - lastIngestionTime; 
  if (timeDelta >= ingestionInterval) {
    
    // Pulse abfragen (ohne den Zähler zu löschen!)
    int16_t currentPulses = 0;
    pcnt_get_counter_value(pcnt_unit, &currentPulses);
    
    // Delta berechnen
    int16_t deltaPulses = currentPulses - prevPulses;
    prevPulses = currentPulses; 
    
    // Overflow abfangen
    if (deltaPulses < 0) {
      deltaPulses = deltaPulses + COUNTER_HIGH_LIMIT;
    }

    // RPM mit Anti-Jitter Mathematik berechnen
    int rpm = deltaPulses * (60000.0 / timeDelta);

    // Payload schnüren (mit Timestamp und Speed!)
    float lat = gps.location.isValid() ? gps.location.lat() : 0.0;
    float lng = gps.location.isValid() ? gps.location.lng() : 0.0;
    float speed = gps.speed.isValid() ? gps.speed.kmph() : 0.0; 
    
    char json[256];
    snprintf(json, sizeof(json), "{\"ts\":%lu,\"rpm\":%d,\"t_m\":%.1f,\"t_e\":%.1f,\"lat\":%.6f,\"lng\":%.6f,\"spd\":%.2f}",
             currentMillis, rpm, currentTempMotor, currentTempESC, lat, lng, speed);

    // Lokales Batch-Logging auf SD-Karte
    File dataFile = SD.open("/log.csv", FILE_APPEND);
    if (dataFile) {
      dataFile.println(json);
      dataFile.close();
    } else {
      Serial.println("Fehler beim Schreiben auf die SD-Karte!");
    }

    lastIngestionTime = currentMillis;
  }
}

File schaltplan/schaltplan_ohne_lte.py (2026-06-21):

import graphviz

def erstelle_perfekten_offline_loetplan_30pin():
    dot = graphviz.Digraph('Offline_Schaltplan', filename='Schaltplan_Offline_30Pin', format='png')
    
    # rankdir='LR' erzwingt den horizontalen Fluss.
    dot.attr(rankdir='LR', splines='polyline', nodesep='1.0', ranksep='4.0')
    dot.attr('node', shape='none', fontname='Helvetica', fontsize='12')

    # 1. ESP32 ZENTRALE (Jetzt im korrekten 30-Pin Design!)
    esp32_html = '''<
    <TABLE BORDER="1" CELLBORDER="1" CELLSPACING="0" CELLPADDING="6">
      <TR><TD COLSPAN="3" BGCOLOR="#add8e6"><B>ESP32 30-Pin (FREENOVE Board)</B></TD></TR>
      <TR><TD BGCOLOR="#d3d3d3"><B>Linke Pins</B></TD><TD BGCOLOR="#e0e0e0" ROWSPAN="11"> ESP32 <br/> Core </TD><TD BGCOLOR="#d3d3d3"><B>Rechte Pins</B></TD></TR>
      <TR><TD PORT="vin">VIN (5V In)</TD><TD PORT="3v3">3V3 (3.3V Out)</TD></TR>
      <TR><TD PORT="gnd_l">GND (Masse)</TD><TD PORT="gnd_r">GND (Masse)</TD></TR>
      <TR><TD>---</TD><TD PORT="d2">D2 (Hall-Sensor)</TD></TR>
      <TR><TD>---</TD><TD PORT="d4">D4 (1-Wire Temp)</TD></TR>
      <TR><TD>---</TD><TD PORT="rx2">RX2 / GPIO16</TD></TR>
      <TR><TD>---</TD><TD PORT="tx2">TX2 / GPIO17</TD></TR>
      <TR><TD>---</TD><TD PORT="d5">D5 (SD CS)</TD></TR>
      <TR><TD>---</TD><TD PORT="d18">D18 (SD SCK)</TD></TR>
      <TR><TD>---</TD><TD PORT="d19">D19 (SD MISO)</TD></TR>
      <TR><TD>---</TD><TD PORT="d23">D23 (SD MOSI)</TD></TR>
    </TABLE>>'''
    dot.node('ESP', label=esp32_html)

    # 2. KOMPONENTEN LINKE SEITE (Nur noch Stromversorgung)
    rx_html = '''<
    <TABLE BORDER="1" CELLBORDER="1" CELLSPACING="0" CELLPADDING="6">
      <TR><TD BGCOLOR="#90ee90"><B>RC Empfänger (BEC)</B></TD></TR>
      <TR><TD PORT="v5">5V (Rot)</TD></TR>
      <TR><TD PORT="gnd">GND (Schwarz)</TD></TR>
      <TR><TD PORT="signal">Signal (Nicht genutzt)</TD></TR>
    </TABLE>>'''

    with dot.subgraph() as s_left:
        s_left.attr(rank='same')
        s_left.node('RX', label=rx_html)

    # 3. KOMPONENTEN RECHTE SEITE (Alle Sensoren + SD Karte)
    sd_html = '''<
    <TABLE BORDER="1" CELLBORDER="1" CELLSPACING="0" CELLPADDING="6">
      <TR><TD BGCOLOR="#d3d3d3"><B>MicroSD (SPI)</B></TD></TR>
      <TR><TD PORT="vcc">VCC (3.3V)</TD></TR>
      <TR><TD PORT="gnd">GND</TD></TR>
      <TR><TD PORT="mosi">MOSI</TD></TR>
      <TR><TD PORT="miso">MISO</TD></TR>
      <TR><TD PORT="sck">SCK</TD></TR>
      <TR><TD PORT="cs">CS</TD></TR>
    </TABLE>>'''

    gps_html = '''<
    <TABLE BORDER="1" CELLBORDER="1" CELLSPACING="0" CELLPADDING="6">
      <TR><TD BGCOLOR="#87cefa"><B>GPS BN-220</B></TD></TR>
      <TR><TD PORT="vcc">VCC (3.3V via WAGO)</TD></TR>
      <TR><TD PORT="gnd">GND</TD></TR>
      <TR><TD PORT="tx">TX (Senden)</TD></TR>
      <TR><TD PORT="rx">RX (Empfang)</TD></TR>
    </TABLE>>'''

    temp_mot_html = '''<
    <TABLE BORDER="1" CELLBORDER="1" CELLSPACING="0" CELLPADDING="6">
      <TR><TD BGCOLOR="#ffffe0"><B>DS18B20 (Motor)</B></TD></TR>
      <TR><TD PORT="vcc">VDD (3.3V via WAGO)</TD></TR>
      <TR><TD PORT="gnd">GND</TD></TR>
      <TR><TD PORT="dq">Data (Gelb/Blau)</TD></TR>
    </TABLE>>'''

    temp_esc_html = '''<
    <TABLE BORDER="1" CELLBORDER="1" CELLSPACING="0" CELLPADDING="6">
      <TR><TD BGCOLOR="#ffffe0"><B>DS18B20 (ESC)</B></TD></TR>
      <TR><TD PORT="vcc">VDD (3.3V via WAGO)</TD></TR>
      <TR><TD PORT="gnd">GND</TD></TR>
      <TR><TD PORT="dq">Data (Gelb/Blau)</TD></TR>
    </TABLE>>'''

    hall_html = '''<
    <TABLE BORDER="1" CELLBORDER="1" CELLSPACING="0" CELLPADDING="6">
      <TR><TD BGCOLOR="#ffb6c1"><B>A3144 Hall-Sensor</B></TD></TR>
      <TR><TD PORT="vcc">1: VCC (3.3V via WAGO)</TD></TR>
      <TR><TD PORT="gnd">2: GND</TD></TR>
      <TR><TD PORT="out">3: DOUT (Signal)</TD></TR>
    </TABLE>>'''

    with dot.subgraph() as s_right:
        s_right.attr(rank='same')
        s_right.node('SD', label=sd_html)
        s_right.node('GPS', label=gps_html)
        s_right.node('TEMP_MOT', label=temp_mot_html)
        s_right.node('TEMP_ESC', label=temp_esc_html)
        s_right.node('HALL', label=hall_html)
        s_right.edge('SD', 'GPS', style='invis')
        s_right.edge('GPS', 'TEMP_MOT', style='invis')
        s_right.edge('TEMP_MOT', 'TEMP_ESC', style='invis')
        s_right.edge('TEMP_ESC', 'HALL', style='invis')

    # --- VERKABELUNG ---

    # LINKE SEITE -> Strom von RC zu ESP
    dot.edge('RX:v5:e', 'ESP:vin:w', color='red', penwidth='3', dir='none')
    dot.edge('RX:gnd:e', 'ESP:gnd_l:w', color='black', penwidth='3', dir='none')
    
    # RECHTE SEITE -> Daten & 3.3V Routing
    
    # SD Karte (VCC an 3.3V)
    dot.edge('ESP:3v3:e', 'SD:vcc:w', color='red', style='dashed', penwidth='2', dir='none')
    dot.edge('ESP:gnd_r:e', 'SD:gnd:w', color='black', penwidth='2', dir='none')
    dot.edge('ESP:d23:e', 'SD:mosi:w', color='blue', penwidth='2', dir='none')
    dot.edge('ESP:d19:e', 'SD:miso:w', color='blue', penwidth='2', dir='none')
    dot.edge('ESP:d18:e', 'SD:sck:w', color='blue', penwidth='2', dir='none')
    dot.edge('ESP:d5:e', 'SD:cs:w', color='blue', penwidth='2', dir='none')

    # GPS (UART Überkreuzt)
    dot.edge('ESP:3v3:e', 'GPS:vcc:w', color='red', style='dashed', penwidth='2', dir='none')
    dot.edge('ESP:gnd_r:e', 'GPS:gnd:w', color='black', penwidth='2', dir='none')
    dot.edge('ESP:rx2:e', 'GPS:tx:w', color='magenta', penwidth='2', dir='none') 
    dot.edge('ESP:tx2:e', 'GPS:rx:w', color='purple', penwidth='2', dir='none')  

    # Motor Temp
    dot.edge('ESP:3v3:e', 'TEMP_MOT:vcc:w', color='red', style='dashed', penwidth='2', dir='none')
    dot.edge('ESP:gnd_r:e', 'TEMP_MOT:gnd:w', color='black', penwidth='2', dir='none')
    dot.edge('ESP:d4:e', 'TEMP_MOT:dq:w', color='orange', penwidth='2', dir='none')

    # ESC Temp
    dot.edge('ESP:3v3:e', 'TEMP_ESC:vcc:w', color='red', style='dashed', penwidth='2', dir='none')
    dot.edge('ESP:gnd_r:e', 'TEMP_ESC:gnd:w', color='black', penwidth='2', dir='none')
    dot.edge('ESP:d4:e', 'TEMP_ESC:dq:w', color='orange', penwidth='2', dir='none')

    # Hall Sensor
    dot.edge('ESP:3v3:e', 'HALL:vcc:w', color='red', style='dashed', penwidth='2', dir='none')
    dot.edge('ESP:gnd_r:e', 'HALL:gnd:w', color='black', penwidth='2', dir='none')
    dot.edge('ESP:d2:e', 'HALL:out:w', color='green', penwidth='2', dir='none')

    dot.render(view=False)
    print("Aktualisierter 30-Pin Lötplan (SD-Karte an 3.3V!) generiert!")

if __name__ == '__main__':
    erstelle_perfekten_offline_loetplan_30pin()
    

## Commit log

2026-03-23 Enhance circuit diagram with detailed component records
    Updated the circuit diagram generation to use detailed records for components and improved the connections between them.
2026-03-24 feat: add 2nd temp sensor
2026-04-23 Update Powerbank model in shopping list
2026-04-24 Add main_offline.cpp for offline data logging
    Implement offline logging functionality with GPS and temperature sensors.
2026-04-24 Refactor offline solder plan for 30-pin design
2026-04-24 feat: Schaltplan 30 pin
2026-04-28 Add README for CAD housing solution STL files
2026-04-30 Update readme with ESP32 case source link
    Added source link for ESP32 case design.
2026-05-01 Enhance readme with project details and acknowledgments
    Updated the readme to provide detailed information about the ESP32 sensor station project, including 3D models, supported hardware, and acknowledgments.
2026-05-01 Fix filename typo for sensor_board.stl
2026-05-01 Fix filename reference in readme.md
    Corrected the filename from 'sensor_board.stl' to 'sensor_board_.stl' in the documentation.
2026-06-21 feat: document project components and implement automated schematic generation for the ESP32 offline logger
2026-06-21 docs: add hardware documentation and wiring schematic for the RC telemetry system
2026-06-21 docs: add readme for RC telemetry system circuit documentation
2026-06-21 Delete Mermaid diagram from schaltplan readme
    Removed Mermaid diagram for circuit layout from readme.
2026-06-21 docs: update hardware documentation to reflect the use of ESP32 terminal breakout boards for vibration-resistant wiring
